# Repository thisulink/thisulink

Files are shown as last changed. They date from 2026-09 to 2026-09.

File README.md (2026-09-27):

# THISULINK™ — Enterprise Diabetic Complication Screening & Tele-Triage Platform

THISULINK™ is a closed-loop clinical network for diabetic complication
screening. It connects routine home monitoring, frontline point-of-care
diagnostics and specialist tele-consultation into one continuous pathway, with
an automated four-tier triage engine deciding where scarce clinical attention
goes.

The platform screens for the two complications that cause the most avoidable
harm and are the least visible on examination: **diabetic foot ulceration**,
detected through plantar shear-wave elastography and contralateral
thermography, and **diabetic retinopathy**, detected through non-mydriatic
fundus imaging with on-device AI grading.

**Status: deployed and operational**, with a hardened backend, verified
role-based access control and an end-to-end validated triage loop.

---

## 1. System architecture

```
 ┌──────────────────────────── TIER 1 · HOME ───────────────────────────────┐
 │  Patient Health Companion                                                │
 │  COTS BP cuff (0x1810) · glucometer (0x1808) · adherence · AI diet       │
 └────────────────────────────────┬─────────────────────────────────────────┘
                                  │ daily vitals
                                  ▼
 ┌──────────────────────── TIER 2 · POINT OF CARE ──────────────────────────┐
 │  Clinical Diagnostic Suite — community health worker                     │
 │                                                                          │
 │   Plantar probe (BLE 0xFFE0)        20D retinal adapter                  │
 │   • VCA 10–300 Hz sweep             • non-mydriatic, 60 s                │
 │   • dual ADXL355, Δx = 40 mm        • EfficientNet-B0 INT8 on-device     │
 │   • TAL221 interlock 1.40–1.60 N    • ICDR grade 0–4                     │
 │   • MLX90621 16×4 FIR, ΔT ≥ 2.2 °C                                       │
 │                                                                          │
 │   Offline-first · encrypted local store · queue and retry                │
 └────────────────────────────────┬─────────────────────────────────────────┘
                                  │ encounter upload
                                  ▼
 ┌──────────────────────── TIER 3 · CLOUD ENGINE ───────────────────────────┐
 │  PocketBase enterprise core — https://pb.thisulink.xyz                   │
 │                                                                          │
 │   Authentication & zero-trust RBAC   Automated triage engine             │
 │   Realtime event bus (SSE)           Immutable audit trail               │
 │   Clinical file storage              Escalation dispatch                 │
 └────────────────────────────────┬─────────────────────────────────────────┘
                                  │ realtime, risk-ranked
                                  ▼
 ┌──────────────────────── TIER 4 · SPECIALIST ─────────────────────────────┐
 │  Clinical Workstation — https://thisulink.xyz                            │
 │                                                                          │
 │   🔴 Critical → 🟠 Priority → 🟡 Moderate → 🟢 Stable                     │
 │   Waveform & FFT review · fundus grading & override                      │
 │   Signed prescriptions · diet approval · LiveKit consultation            │
 └──────────────────────────────────────────────────────────────────────────┘
```

The loop closes: every reading triggers a server-side triage recomputation,
which updates the patient's tier, writes an audit row, and — on escalation into
a priority tier — dispatches an alert back to the health worker in the field.

---

## 2. Production endpoints

| Endpoint | Serves | TLS | Status |
|---|---|---|---|
| **https://thisulink.xyz** | Specialist Clinical Workstation | Cloudflare edge | **200** |
| **https://doctor.thisulink.xyz** | Workstation, named ingress | Cloudflare edge | **200** |
| **https://pb.thisulink.xyz** | Backend REST + realtime gateway | Cloudflare edge | **200** |
| `https://pb.thisulink.xyz/_/` | Administration console | — | **404 — blocked at edge** |
| `http://<tailscale-ip>:8090/_/` | Administration console | Private mesh | Mesh only |

### Edge security rules

| Rule | Enforcement |
|---|---|
| `/_/*` returns 404 publicly | Reverse proxy at the origin |
| `/api/admins` returns 404 publicly | Reverse proxy at the origin |
| No inbound ports on the origin | Outbound-initiated Cloudflare tunnel |
| Default-deny firewall | Mesh interface and SSH only |
| Administration access | Private Tailscale mesh exclusively |

Full topology and operations: **[backend/INFRASTRUCTURE.md](backend/INFRASTRUCTURE.md)**

---

## 3. Access credentials

| Role | Endpoint | Email | Password |
|---|---|---|---|
| **Physician** | https://thisulink.xyz | `doctor@thisulink.xyz` | `Doctor@Thisu2026` |
| **Health worker** | Clinical Diagnostic Suite (Android) | `healthworker@thisulink.xyz` | `Worker@Thisu2026` |
| **Patient** | Health Companion *(roadmap)* | `patient@thisulink.xyz` | `Patient@Thisu2026` |
| **Administrator** | `http://<tailscale-ip>:8090/_/` | `admin@thisulink.xyz` | `AdminSecure#2026` |

**Patient ABHA:** `9145-2388-9100-21`

> The administration console is unreachable from the public internet by design.
> Rotate every credential above before any deployment carrying real patient
> data — they are published here for evaluation.

### Verified access isolation

| Account | patients | plantar | vitals | retinal |
|---|---|---|---|---|
| `doctor` | 4 | 24 | 24 | 4 |
| `health_worker` | 4 | 24 | 24 | 4 |
| **`patient`** | **0** | **0** | **0** | **0** |

---

## 4. Documentation index

| # | Document | Subsystem |
|---|---|---|
| 1 | **This file** | Master architecture & deployment directory |
| 2 | [hardware/README.md](hardware/README.md) | Foot platform — actuator, interlock, sensor geometry, thermal array |
| 3 | [hardware/BLE_SPECIFICATION.md](hardware/BLE_SPECIFICATION.md) | 73-byte telemetry contract, GATT profile, CRC |
| 4 | [vitals-monitor/README.md](vitals-monitor/README.md) | COTS BLE vitals — `0x1810` / `0x1808` |
| 5 | [retinal-screening/README.md](retinal-screening/README.md) | 20D adapter, quality gate, edge AI pipeline |
| 6 | [software/README.md](software/README.md) | Cross-platform client architecture |
| 7 | [software/daq-dashboard/README.md](software/daq-dashboard/README.md) | Frontline screening suite |
| 8 | [software/patient-app/README.md](software/patient-app/README.md) | Patient companion & daily compliance |
| 9 | [doctor-portal/README.md](doctor-portal/README.md) | Specialist workstation & triage workflows |
| 10 | [backend/README.md](backend/README.md) | Schema, RBAC, event engine |
| 11 | [backend/INFRASTRUCTURE.md](backend/INFRASTRUCTURE.md) | Tunnel, mesh, edge operations |
| 12 | [prototype-outputs/README.md](prototype-outputs/README.md) | Screen-by-screen prototype outputs & verification gallery |
| 13 | [firmware/README.md](firmware/README.md) | Embedded MCU firmware architecture (ESP32-S3 + DSP pipeline) |
| 14 | [platform matlab simulation and proofs/README.md](platform%20matlab%20simulation%20and%20proofs/README.md) | Plantar SWE simulation suite & mathematical proofs (12 experiments) |
| 15 | [Clinical_Datasets_and_Parameter_Conversion/README.md](Clinical_Datasets_and_Parameter_Conversion/README.md) | Clinical data sourcing, Kelvin-Voigt physics & parameter conversion |
| 16 | [hardware/cad/README.md](hardware/cad/README.md) | Prototype 3D CAD models, cross-sections & mechanical engineering specs |

### Specification ↔ source

The documentation tree is organised by **subsystem**; the source tree is
organised by **build artefact**. They map as follows:

| Specification | Implementation |
|---|---|
| `software/daq-dashboard/` | `thisulink_app` (Flutter, Android client) |
| `doctor-portal/` | `doctor_portal` (Flutter, Web workstation) |
| `backend/` | [`deploy/`](deploy/) — provisioning, schema, automation |
| `hardware/`, `vitals-monitor/`, `retinal-screening/` | Hardware & clinical telemetry contracts |

---

## 5. Resolved specification conflicts

Four conflicts across earlier drafts are closed. These resolutions are binding.

| # | Conflict | Resolution |
|---|---|---|
| 1 | **BLE frame header** | **`0x5448`** (ASCII `"TH"`). The draft value `0xDA 0x7A` is **permanently deprecated** and must not appear in firmware, clients, fixtures or documentation. |
| 2 | **Blood pressure sensing** | **COTS oscillometric devices** over Bluetooth SIG `0x1810`, ISO 81060-2 validated. The cuffless optical PPG model is **removed** — it has no accepted validation standard and fails by returning a plausible wrong number. |
| 3 | **Thermal sensing** | **Melexis MLX90621**, 16 × 4 = 64-pixel FIR array. Alert on contralateral asymmetry **ΔT ≥ 2.2 °C** (Lavery et al., 2007). |
| 4 | **Authorisation model** | **Explicit allowlist** on `@request.auth.role`. Negative exclusion rules are prohibited — see below. |

### Why the authorisation model is a resolution, not a preference

A negative exclusion (`role != "patient"`) evaluates **true** when `role` is
absent. During production verification this admitted every authenticated
account to every clinical collection, because a schema defect meant no account
had a role at all. A patient account could read all 24 plantar records, 24
vitals, 4 fundus evaluations and 8 triage results.

An allowlist denies the same account. The two forms behave **oppositely**
under exactly the condition nobody writes a test for. Full incident analysis:
[backend/README.md §4.1](backend/README.md).

---

## 6. Clinical triage specification

| Tier | Condition — first match wins | Action |
|---|---|---|
| 🔴 **RED** | Tissue class C, **or** P(referable) ≥ 0.50 with ICDR ≥ 3, **or** glucose > 400 mg/dL | Refer urgently |
| 🟠 **ORANGE** | Class B with ΔT ≥ 2.2 °C, **or** P(referable) ≥ 0.50, **or** glucose > 300 | Escalate to specialist |
| 🟡 **YELLOW** | Class B, **or** ΔT ≥ 2.2 °C, **or** ICDR ≥ 2, **or** glucose > 180 | Monitor, recheck next cycle |
| 🟢 **GREEN** | None of the above | No action |

### Clinical constants

| Constant | Value | Governs |
|---|---|---|
| Preload interlock | **1.40 – 1.60 N** | Scan validity |
| Thermal asymmetry alert | **ΔT ≥ 2.2 °C** | Ulcer-risk escalation |
| Referable DR threshold | **P ≥ 0.50** | Retinal escalation |
| Excitation sweep | **10 – 300 Hz** | Shear-wave acquisition |
| Pickup baseline | **Δx = 40 mm** (x₁ 105 mm, x₂ 145 mm) | Phase velocity |
| Screening cycle | **6 days** | Fundus on days 1 and 4 |
| Relay escalation | **4 hours** | Unacknowledged priority tier |

---

## 7. Verification status

### Verified against the live deployment

| Check | Result |
|---|---|
| Static analysis — both shipped clients | Clean |
| Automated tests — field client | **63 passing** |
| Schema provisioning | 8 collections, rules confirmed in database |
| **Role-based access isolation** | **Verified — patient sees zero clinical records** |
| **Triage engine, end to end** | **Correct tier for every patient** |
| **Escalation dispatch** | **Alert raised on tier entry with clinical reasoning** |
| Administration console exposure | 404 public, mesh-only |
| Public endpoints | 3 hostnames serving |

### Verified tier assignment

| Patient | Tissue | ΔT | Glucose | ICDR | Tier |
|---|---|---|---|---|---|
| Meena Devi | C | 2.7 °C | 262 | 4 | 🔴 RED |
| Saravanan S | B | 2.4 °C | 216 | 2 | 🟠 ORANGE |
| Ravi Kumar | B | 1.9 °C | 168 | 1 | 🟡 YELLOW |
| Arjun Prakash | A | 1.2 °C | 138 | 0 | 🟢 GREEN |

### Outstanding before clinical use

| Item | Status |
|---|---|
| **Probe firmware validation** | Decoder byte-exact and tested; never run against physical hardware |
| **Retinal model asset** | Inference pipeline implemented; trained INT8 model not bundled |
| **Retinal image quality gate** | Not implemented — required before grading is trusted |
| **Tele-consultation token service** | Not deployed; consultations cannot start |
| **Patient Health Companion** | Not implemented; backend role and record are live |
| **Database backups** | **Not configured** |
| **Redundancy** | **Single node** |

---

## 8. Quickstart

### Backend

```bash
curl -s https://pb.thisulink.xyz/api/health
sudo systemctl status thisulink-pocketbase
```

### Specialist Clinical Workstation

```bash
cd doctor_portal
flutter pub get && cp .env.example .env
flutter run -d chrome --web-port=8080
flutter build web --release
```

### Clinical Diagnostic Suite

```bash
cd thisulink_app
flutter pub get
dart run build_runner build
flutter run                           # live backend
flutter run --dart-define=DEMO=true   # seeded, no backend required
flutter test                          # 63 tests
```

### Provisioning a new node

```bash
sudo ./deploy/bootstrap.sh --purge-existing --apply-ingress
sudo ./deploy/finish.sh
sudo ./deploy/seed.sh
./deploy/verify.sh
```

---

## 9. Regulatory positioning

THISULINK™ is **clinical decision support**. It stratifies risk and presents
evidence; a licensed clinician makes every clinical decision. That boundary is
enforced in the product — the intended-use notice is present on every page of
the workstation, physician override supersedes every AI output, and no tier is
communicated to a patient without a clinician.

Documentation is structured for **IEC 62304** alignment: each subsystem carries
a controlled specification, interfaces are contract-specified before
implementation, and verification status is stated per component rather than in
aggregate.

---

<div align="center">

**THISULINK™** · Clinical decision support for diabetic complication screening
Screening outputs are authorised by a licensed clinician.

</div>

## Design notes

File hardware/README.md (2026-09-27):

# THISULINK™ Plantar Diagnostic Platform — Hardware Specification

| | |
|---|---|
| **Document** | HW-SPEC-001 |
| **Subsystem** | Plantar Shear-Wave Elastography & Thermography Platform |
| **Wire contract** | [BLE_SPECIFICATION.md](BLE_SPECIFICATION.md) |
| **Status** | Design specification — see §9 for build status |

---

## 1. Clinical purpose

Diabetic foot ulceration is preceded by changes that are invisible on
inspection: the plantar soft tissue stiffens as collagen glycates, and a
developing inflammatory focus raises local temperature before any break in the
skin. Both are measurable non-invasively, and both are missed by a visual
screening exam.

The platform measures two independent physical signals at the same site in the
same sitting:

| Signal | Physical basis | Clinical meaning |
|---|---|---|
| **Shear-wave speed / Young's modulus** | Surface wave propagation through plantar soft tissue | Tissue stiffening from advanced glycation end-product accumulation |
| **Contralateral thermal asymmetry ΔT** | Non-contact far-infrared emission | Localised inflammation preceding ulceration |

Neither measurement diagnoses. Together they stratify risk, and the platform's
job is to make that stratification reproducible enough that a health worker
with a week of training produces the same numbers as a clinician.

---

## 2. Architecture

```
                 THISULINK PLANTAR PLATFORM
    ┌──────────────────────────────────────────────────────┐
    │                                                      │
    │   ┌────────────┐         PLANTAR SURFACE             │
    │   │  MLX90621  │  ◄── non-contact FIR, 16×4          │
    │   │  16×4 FIR  │      64 pixels, contralateral ΔT    │
    │   └────────────┘                                     │
    │                                                      │
    │   ═══════════════════════════════════════════        │
    │        ▲             ▲                ▲              │
    │        │             │                │              │
    │   ┌────┴────┐   ┌────┴────┐     ┌─────┴─────┐        │
    │   │   VCA   │   │ ADXL355 │     │  ADXL355  │        │
    │   │ 10–300Hz│   │ pickup 1│     │  pickup 2 │        │
    │   │ 0.100 N │   │ x₁=105mm│     │  x₂=145mm │        │
    │   └─────────┘   └─────────┘     └───────────┘        │
    │                 └──── Δx = 40 mm baseline ────┘      │
    │                                                      │
    │   ┌──────────────────────────────────────┐           │
    │   │  TAL221 load cell  →  HX711 24-bit   │           │
    │   │  preload interlock 1.40 – 1.60 N     │           │
    │   └──────────────────────────────────────┘           │
    │                                                      │
    │   ┌──────────────────────────────────────┐           │
    │   │  MCU · BLE 5.0 · GATT 0xFFE0         │           │
    │   │  73-byte frame @ 0xFFE1 (notify)     │           │
    │   └──────────────────────────────────────┘           │
    └──────────────────────────────────────────────────────┘
                              │
                              ▼  BLE 5.0
                   Clinical Diagnostic Suite (tablet)
```

---

## 3. Excitation — voice coil actuator

| Parameter | Value |
|---|---|
| Actuator type | Voice coil (VCA), direct-drive |
| Sweep range | **10 – 300 Hz** |
| Dynamic force | **0.100 N** |
| Sweep duration | 200 ms per acquisition |
| Coupling | Medical-grade silicone pad |

The band is chosen for tissue, not convenience. Below ~10 Hz the response is
dominated by bulk limb motion; above ~300 Hz attenuation in soft tissue makes
the second pickup's signal-to-noise unusable across a 40 mm baseline.

Dynamic force is held at 0.100 N — two orders below the static preload — so the
excitation perturbs the tissue without changing the loading state being
measured.

---

## 4. Preload interlock

| Component | Specification |
|---|---|
| Load cell | TAL221 cantilever, 5 kg (≈50 N) capacity |
| ADC | HX711, 24-bit, integrated gain |
| Sample rate | 80 SPS |
| **Valid window** | **1.40 N – 1.60 N** |
| Out-of-window behaviour | Sample flagged, excluded from averaging |
| Wander behaviour | Auto-abort if preload leaves the window mid-sweep |

### Why an interlock rather than a correction

Soft tissue is non-linear and load-dependent: its apparent stiffness rises with
applied force. A shear-wave measurement taken at 2.5 N and one at 1.5 N are not
the same measurement with different noise — they are measurements of different
mechanical states.

Two options exist: measure the force and correct for it, or constrain the force
and refuse to measure outside the constraint. The platform constrains, because
correction requires a per-patient tissue model the device does not have. A
rejected scan costs thirty seconds. A silently load-biased scan enters the
clinical record and is indistinguishable from a real finding.

### Tare procedure

The load cell is zeroed via the `TARE` command (§3.2 of the BLE specification)
at rest before each encounter, compensating for platform orientation and
accumulated mechanical drift.

---

## 5. Surface wave sensing

| Parameter | Value |
|---|---|
| Sensors | 2 × Analog Devices ADXL355, low-noise triaxial MEMS |
| Pickup 1 position | x₁ = **105 mm** from actuator axis |
| Pickup 2 position | x₂ = **145 mm** from actuator axis |
| Baseline | **Δx = 40 mm** |
| Sampling | Synchronous, shared clock |

### Phase velocity derivation

Shear-wave speed is computed from the phase difference between the two pickups
at each sweep frequency:

> **cₛ = ω · Δx / Δφ**

where ω is angular excitation frequency, Δx the 40 mm baseline, and Δφ the
measured phase delay.

Young's modulus follows from the shear-wave speed under a near-incompressible
soft-tissue assumption:

> **E ≈ 3ρcₛ²**

with ρ taken as soft-tissue density.

### Why two sensors rather than time-of-flight

A phase-difference measurement across a **fixed, known** baseline is
insensitive to the absolute trigger instant and to actuator latency, both of
which drift with temperature and mechanical wear. A single-sensor
time-of-flight approach inherits every one of those errors directly into the
reported speed.

The baseline is the one dimension that must not move: Δx appears linearly in
cₛ, so a 1 mm mounting error is a 2.5% systematic error in every reading the
device ever produces. Pickup spacing is therefore fixed in the moulded
housing, not adjustable.

---

## 6. Thermal mapping

| Parameter | Value |
|---|---|
| Sensor | **Melexis MLX90621**, far-infrared thermopile array |
| Resolution | **16 × 4 = 64 pixels** |
| Measurement | Non-contact, no thermal loading of the site |
| Field of view | Matched to plantar region of interest |
| **Alert threshold** | **ΔT ≥ 2.2 °C** contralateral asymmetry |

### Contralateral comparison

Absolute plantar temperature varies with ambient conditions, recent activity,
footwear and perfusion — none of which indicate pathology. The clinically
meaningful quantity is the **difference between corresponding sites on the two
feet**, measured in the same session under the same conditions.

The 2.2 °C threshold follows Lavery et al. (2007), which established
contralateral asymmetry at this magnitude as predictive of impending
ulceration. Both feet are imaged in the same encounter; a single-foot capture
cannot produce a valid ΔT and is rejected at the application layer.

### Why a 64-pixel array

A single-point IR thermometer measures wherever it is aimed. An inflammatory
focus is localised, so a point measurement a centimetre away from it reads
normal. The 16×4 array covers the region of interest in one capture, removing
operator aim from the measurement.

---

## 7. Mechanical housing

| Element | Specification |
|---|---|
| Enclosure | 3D-printed PETG |
| Acoustic coupling | Medical-grade silicone interface pad |
| Vibration isolation | Rubberised damping feet |
| Sensor mounting | Rigid, fixed 40 mm pickup baseline |

PETG is specified over PLA for dimensional stability at clinic temperatures and
for its tolerance of repeated surface disinfection.

The damping feet serve the measurement, not comfort: without isolation, the
VCA excitation couples into the examination surface and returns to the pickups
as a structural path parallel to the tissue path, corrupting the phase
difference the entire instrument depends on.

> Complete mechanical engineering CAD models, cross-sectional schematics, and OpenSCAD parametric files: **[cad/README.md](cad/README.md)**.

---

## 8. Interface summary

| Interface | Specification |
|---|---|
| Wireless | Bluetooth Low Energy 5.0 |
| Service | `0xFFE0` |
| Telemetry | `0xFFE1`, notify, 73 bytes |
| Control | `0xFFE2`, write, 4 bytes |
| Frame header | `0x5448` (`"TH"`) |
| Integrity | CRC-8/MAXIM over bytes 0–71 |

Full byte-level contract: **[BLE_SPECIFICATION.md](BLE_SPECIFICATION.md)**.

---

## 9. Implementation status

| Item | Status |
|---|---|
| Mechanical and sensing design | Specified |
| BLE wire contract | Specified, frozen at v1.0 |
| Client-side decoder | Implemented, 18 conformance tests passing |
| Client-side interlock enforcement | Implemented |
| Tissue classification bands | Implemented, unit-tested |
| **Probe firmware** | **Not validated against this document** |
| **End-to-end acquisition on hardware** | **Not yet performed** |

The software half of this interface is complete and tested against the
specification. The specification has not been confirmed against a physical
probe. Section 8 of the BLE specification is the checklist that closes that
gap, and it must be executed on-target before any clinical use.

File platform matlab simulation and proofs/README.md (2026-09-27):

# THISULINK: Plantar Biomechanical SWE Platform — MATLAB Simulation Suite & Engineering Proofs






---

## 1. Executive Summary & Problem Context

**THISULINK** is an integrated dual-modality frontline triage device engineered for **Frontline Health Workers (VHN / ANM / CHO)** to prevent diabetic lower-limb amputations and diabetic retinopathy in under-resourced communities.

This folder contains the **mechanical, biomechanical, electromechanical, and sensor-level simulation suite** (MATLAB / GNU Octave) used to size and sanity-check the **THISULINK Plantar Shear Wave Elastography (SWE) Platform**.

> **Scope:** every result in this folder is a *simulation* with assumed parameters and synthetic data. Nothing here is a bench measurement or clinical evidence. See [Section 8 - Limitations](#8-limitations).

### Why Biomechanical SWE on the Plantar Foot?
Standard clinical triage uses 10-gram monofilaments or tuning forks, which only identify nerve loss after irreversible neuro-ischaemic destruction has occurred. Long before sensory loss, **non-enzymatic glycation** of collagen fibers in the plantar fat pad and fascia causes severe tissue stiffening, loss of energy damping, and elevated shear stresses that cause plantar ulceration.

THISULINK launches non-invasive, low-frequency shear waves ($10 - 300\text{ Hz}$) into the plantar tissue using a precision Voice Coil Actuator (VCA), and tracks wave propagation using dual low-noise digital accelerometers (Analog Devices ADXL355). This allows quantitative extraction of shear wave velocity ($c_s$) and Young's modulus ($E = 3\rho c_s^2$) months before visible lesions or ulceration appear.

```
+---------------------------------------------------------------------------------------+
|                                THISULINK HARDWARE ARCHITECTURE                        |
+---------------------------------------------------------------------------------------+
|                                                                                       |
|   +-------------------+        +--------------------+        +--------------------+   |
|   | Voice Coil (VCA)  |        | Proximal Pickup    |        | Distal Pickup      |   |
|   | 10 - 300 Hz Chirp |=======>| ADXL355 Sensor 1   |=======>| ADXL355 Sensor 2   |   |
|   | F0 = 100 mN       |        | x1 = 105 mm        |        | x2 = 145 mm        |   |
|   +-------------------+        +--------------------+        +--------------------+   |
|            ^                              |                             |             |
|            |                              +--------------+--------------+             |
|            |                                             |                            |
|     +-------------+                        [Phase Difference Delta phi]               |
|     | Load Cell   |                                      |                            |
|     | 1.50 N Gate |                        c_s = (omega * Delta x) / Delta phi        |
|     +-------------+                        E = 3 * rho * c_s^2                        |
|            |                                             |                            |
|    [Preload Interlock]                                   v                            |
|    (1.40 N - 1.60 N)                       +----------------------------+             |
|                                            | THISULINK TRIAGE ENGINE    |             |
|                                            | SWE Modulus + FIR Thermal  |             |
|                                            +----------------------------+             |
+---------------------------------------------------------------------------------------+
```

---

## 2. Platform Mechanical & Hardware Architecture

| Subsystem | Component | Specifications | Clinical / Physical Justification |
|---|---|---|---|
| **Dynamic Actuator** | Linear Voice Coil Actuator (VCA) | $m = 0.045\text{ kg}$, $R = 8.2\ \Omega$, $L = 1.2\text{ mH}$, $K_f = 2.4\text{ N/A}$ | Provides pure decoupled sinusoidal chirp ($10 - 300\text{ Hz}$), eliminating motor harmonic distortion. |
| **Contact Interlock** | Cantilever Micro Load Cell + HX711 | $1.50\text{ N} \pm 0.10\text{ N}$ ($1.40 - 1.60\text{ N}$ allowable gate) | Prevents operator variability and eliminates non-linear hyperelastic tissue pre-compression artifacts. |
| **Pickup Transducers** | Dual ADXL355 Accelerometers | 20-bit ADC, $25\ \mu\text{g}/\sqrt{\text{Hz}}$, $\pm 2.048\text{ g}$, simulated at ODR $4\text{ kHz}$ (LPF $\approx 1\text{ kHz}$) | Simulated 50 Hz phase error $\approx 0.1^\circ$ at the distal pickup (Exp. 06). The current POC firmware uses an ADXL345 at 200 Hz ODR (Nyquist 100 Hz) and cannot cover the full sweep. |
| **Gauge Separation** | Rigid CNC Base Frame | $x_1 = 105\text{ mm}$, $x_2 = 145\text{ mm}$, $\Delta x = 40.0\text{ mm}$ | Inter-sensor phase exceeds $\pi$ above $\approx 46-110\text{ Hz}$ (class dependent), so the sweep must be phase-unwrapped across frequency (Exp. 10). |
| **Tremor Restraint** | Medical Velcro Stabilization Straps | Dual instep & heel belts ($k_{\text{strap}} = 12,000\text{ N/m}$, assumed) | Simulated: an assumed $1.5\text{ mm}$ free-foot tremor ($2 - 5\text{ Hz}$) is reduced to $0.02\text{ mm}$ ($98.7\%$, Exp. 11). |
| **Guide Flexures** | Beryllium Copper Planar Springs | Lateral stiffness $k_{\text{lat}} = 7,500\text{ N/m}$ | Guides normal excitation ($Z$-axis) while clamping rocking and transverse shear motion. |
| **Thermal Sensing** | MLX90621 $16 \times 4$ FIR Array | Differential bilateral sensing, NETD $0.1^\circ\text{C}$ | Detects acute neuropathic inflammation / Charcot warning ($\Delta T_{\text{contra}} \ge 2.2^\circ\text{C}$). |

---

## 3. Plantar Soft-Tissue Biomechanical Classes

The simulation models **three preliminary research mechanical-response bands** of diabetic plantar tissue remodeling ($\rho = 1050\text{ kg/m}^3$). These bands are derived from the Kelvin-Voigt viscoelastic model and literature-sourced tissue parameters — they are not clinically validated stages. Human-subject confirmation against biopsy or established clinical markers has not been performed.

```
+---------------------------------------------------------------------------------------------------------+
|                                    DIAGNOSTIC BIOMECHANICAL CLASSES                                     |
+-------------------+-----------------+-----------------+--------------------+------------------+---------+
| Diagnostic Class  | Contact k (N/m) | Shear Mod. (Pa) | Shear Speed (m/s)  | Young's Modulus  | Damping |
+-------------------+-----------------+-----------------+--------------------+------------------+---------+
| Class 1: Healthy  | 800 N/m         | 14.5 kPa        | 3.72 m/s           | 43.5 kPa         | 2.5 Ns/m|
| Class 2: Early    | 1500 N/m        | 32.0 kPa        | 5.52 m/s           | 96.0 kPa         | 3.2 Ns/m|
| Class 3: Severe   | 2600 N/m        | 68.0 kPa        | 8.05 m/s           | 204.0 kPa        | 4.5 Ns/m|
+-------------------+-----------------+-----------------+--------------------+------------------+---------+
```

---

## 4. Directory Structure & Simulation Modules

```
platform matlab simulation and proofs/
├── master_run_all.m                                  # Runs all 12 experiments, isolated; PASS/FAIL table
├── README.md                                         # This file
├── .gitignore                                        # ignores legacy */results/ folders
├── common/
│   ├── simulation_parameters.m                       # Shared parameters (script; does not clear anything)
│   ├── tissue_model.m                                # 1-DOF Kelvin-Voigt contact ODE
│   ├── shear_wave_propagation_model.m                # 1-D viscoelastic propagation to a pickup (fractional delay)
│   ├── run_experiment_isolated.m                     # Runs one script in its own workspace, restores path/folder
│   ├── det_randn.m                                   # Deterministic normal RNG (same numbers in MATLAB and Octave)
│   ├── fourier_pair.m                                # Coherent single-tone amplitude/phase of two signals
│   ├── results_folder.m                              # outputs/<experiment>/ helper
│   └── bar_colored.m                                 # Per-bar coloured bar chart (MATLAB + Octave)
├── 01_Baseline_Mechanical_Response/                  # 1.5 N preload + 100 mN, 50 Hz response
├── 02_Stiffness_Comparison/                          # Healthy vs early glycation vs neuropathy
├── 03_Frequency_Sweep/                               # 10-300 Hz FRF & resonance shift
├── 04_FFT_Analysis/                                  # Hann-windowed FFT & THD pipeline
├── 05_Sensor_Simulation/                             # Dual ADXL355 digitisation, broadband vs narrow-band SNR
├── 06_Noise_SNR_Analysis/                            # Noise-density sweep, 50 Hz phase error
├── 07_Contact_Force_Sensitivity/                     # Preload stiffening & 1.50 N interlock window
├── 08_Load_Cell_Validation/                          # Load-cell interlock decision logic
├── 09_VCA_Electrical_Test/                           # VCA impedance, current, force, power
├── 10_Shear_Wave_Dispersion_and_Modulus/             # Phase velocity, unwrapping, Kelvin-Voigt modulus fit
├── 11_Velcro_and_Flexure_Tremor_Suppression/         # Tremor suppression by straps + flexures
├── 12_Comprehensive_Triage_Scoring/                  # SWE + thermal triage on a synthetic cohort
└── outputs/                                          # Generated figures + run log - see outputs/README.md
```

---

## 5. Mathematical Formulations & Derivations

### 5.1 Kelvin-Voigt Viscoelastic Wave Propagation
Plantar tissue dynamics under harmonic voice coil excitation:
$$m \ddot{x}(t) + c \dot{x}(t) + k x(t) = F_0 \sin(\omega t)$$

Complex shear modulus:
$$G^*(\omega) = \mu + j \omega \eta$$

Viscoelastic phase velocity $c_s(\omega)$ and spatial attenuation $\alpha(\omega)$:
$$c_s(\omega) = \sqrt{\frac{2(\mu^2 + \omega^2 \eta^2)}{\rho\left(\mu + \sqrt{\mu^2 + \omega^2 \eta^2}\right)}}$$
$$\alpha(\omega) = \sqrt{\frac{\rho \omega^2\left(\sqrt{\mu^2 + \omega^2 \eta^2} - \mu\right)}{2(\mu^2 + \omega^2 \eta^2)}}$$

### 5.2 Dual Pickup Phase Difference Method
Given two ADXL355 pickups at $x_1 = 105\text{ mm}$ and $x_2 = 145\text{ mm}$ ($\Delta x = 40.0\text{ mm}$):
$$\Delta \phi(\omega) = \angle X_1(\omega) - \angle X_2(\omega) \quad (\text{distal lags proximal})$$
$$c_s(\omega) = \frac{\omega \cdot \Delta x}{\Delta \phi(\omega)}$$

**Phase wrapping:** $\Delta\phi$ exceeds $\pi$ above $f = c_s/2\Delta x$ (about 46-110 Hz for $c_s$ = 3.7-8 m/s) and $2\pi$ above $f = c_s/\Delta x$. Experiment 10 measures a stepped sine from 20 Hz and unwraps along frequency; a single-frequency estimate is only safe at low frequency (50 Hz is used for the nominal measurement).

Plantar tissue Young's Modulus $E$ (for nearly incompressible tissue $\nu \approx 0.499$):
$$E \approx 3\mu = 3\rho \cdot c_s^2$$

### 5.3 Tremor Suppression Model (Velcro Straps + Flexures)
$$\left(m_{\text{foot}}\right) \ddot{x} + \left(c_{\text{free}} + c_{\text{strap}}\right) \dot{x} + \left(k_{\text{free}} + k_{\text{strap}} + k_{\text{flex}}\right) x = F_{\text{tremor}}(t)$$

With THISULINK restraints:
$$k_{\text{eff}} = 500 + 12000 + 7500 = \mathbf{20,000\text{ N/m}} \quad (\text{40-fold rigidity increase})$$
With an assumed $1.50\text{ mm}$ free-foot tremor, the simulated clamped amplitude is $0.0195\text{ mm}$ ($98.7\%$ attenuation, Experiment 11).

---

## 6. How to Run the Simulations

### Prerequisites
- MATLAB R2018b or newer (uses `xline`/`yline`), **no toolboxes required**, or
- GNU Octave (tested with **11.3**, no packages required).

### Whole suite
```matlab
% from the folder "platform matlab simulation and proofs"
master_run_all
```
```bash
matlab -batch "master_run_all"
octave --no-gui --eval "master_run_all"   # Windows: use octave-gui.exe --no-gui (qt) so PNG export works
```
- Each experiment runs in its own workspace (`common/run_experiment_isolated.m`); the path and current folder are restored afterwards, a failing experiment is reported and the suite continues.
- Figures go to `outputs/<experiment>/`, the console log to `outputs/master_run_log.txt`. The committed copies
  are indexed with captions in **[outputs/README.md](outputs/README.md)**; re-running the suite overwrites them.
- Runtime ~30 s. On Windows keep the clone path short: Octave cannot write files whose full path exceeds 260 characters.

### Expected output (GNU Octave 11.3, Windows)
```
Exp  Module                                       Result  Time (s)
01   01_Baseline_Mechanical_Response              PASS        2.24
02   02_Stiffness_Comparison                      PASS        3.01
03   03_Frequency_Sweep                           PASS        1.79
04   04_FFT_Analysis                              PASS        1.01
05   05_Sensor_Simulation                         PASS        1.79
06   06_Noise_SNR_Analysis                        PASS        1.68
07   07_Contact_Force_Sensitivity                 PASS        1.99
08   08_Load_Cell_Validation                      PASS        1.53
09   09_VCA_Electrical_Test                       PASS        1.82
10   10_Shear_Wave_Dispersion_and_Modulus         PASS        4.55
11   11_Velcro_and_Flexure_Tremor_Suppression     PASS        2.21
12   12_Comprehensive_Triage_Scoring              PASS        2.31
Passed: 12 / 12
```
"PASS" means the script ran to completion without error; the engineering checks each experiment prints are listed in its README.

### Running individual experiments
```matlab
cd('10_Shear_Wave_Dispersion_and_Modulus')
experiment_shear_wave
```

---

## 7. Simulation Evidence Index

All figures below are outputs of the scripts with the parameters in `common/simulation_parameters.m`.

| Topic | Simulated result | Experiment |
|---|---|---|
| Motion amplitude | 50 Hz steady-state displacement 0.027 mm (healthy) to 0.043 mm (neuropathy) at $F_0$ = 100 mN | 01, 02 |
| Resonance shift | $f_n$ 21.2 → 29.1 → 38.3 Hz; acceleration FRF peaks at 22 / 30 / 40 Hz | 02, 03 |
| Sensor noise | 50 Hz phase error ≈ 0.1° at 25 µg/√Hz; narrow-band SNR ≈ 55 dB at the distal pickup (broadband 18 dB) | 05, 06 |
| Preload control | 0.8-3.0 N gives -15.8 % to +33.8 % stiffness error; inside 1.40-1.60 N ≤ 2.25 % (assumed linear stiffening) | 07, 08 |
| Actuator power | 87.6 mW coil dissipation at 1.20 V; only 0.34 V needed for 100 mN (static-coil model) | 09 |
| Modulus reconstruction | 50 Hz apparent $E$ biased +1 to +5 % by viscosity; Kelvin-Voigt fit over the unwrapped usable band recovers $E$ within 1 % (same model used to generate the data) | 10 |
| Usable band | attenuation limits distal SNR ≥ 20 dB to 20-100 / 140 / 200 Hz (healthy / early / neuropathy) | 10 |
| Tremor suppression | assumed 1.5 mm free tremor → 0.0195 mm clamped (98.7 %, 39 dB in 2-5 Hz) | 11 |
| Triage rules | **SIMULATION on synthetic data:** 99.17 % 4-class agreement (119/120), Charcot flag 100 % sens./spec. on a synthetic N = 120 cohort. Not clinical accuracy. | 12 |

The previously quoted "94.2 % diagnostic accuracy, 100 % sensitivity" is withdrawn: it came from an older script version, was not reproducible, and in any case described synthetic data only.

---

## 8. Limitations
- **Parameters are assumptions.** Tissue classes ($k$, $c$, $\mu$, $\eta$), strap/flexure stiffness, preload stiffening coefficient and cohort distributions are literature-inspired placeholders, not measurements.
- **Simplified physics.** 1-DOF contact model; 1-D narrow-band Kelvin-Voigt propagation with geometric spreading; no tissue layering, boundaries, finite contact size, skin coupling or sensor mounting dynamics.
- **Inverse crime.** Experiments 10 and 12 reconstruct data with the same model that generated it, so their accuracy figures are upper bounds.
- **Hardware.** The simulated sensor is the production dual-ADXL355 probe (ODR 4 kHz). The only existing firmware (ESP32-S3 + ADXL345, 200 Hz ODR, Nyquist 100 Hz) cannot sample the 10-300 Hz sweep. Actuator back-EMF and electronics power are not modelled.
- **No clinical claims.** Triage metrics describe separation of synthetic groups; clinical sensitivity/specificity require a prospective study.

---

## 9. Authors & License
**Project THISULINK**
Integrated Dual-Modality Frontline Diabetic Triage
Smart India Hackathon (SIH) 2026 Grand Finale
Repository: [https://github.com/thisulink/thisulink](https://github.com/thisulink/thisulink)
Licensed under the MIT License.

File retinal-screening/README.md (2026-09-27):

# THISULINK™ Retinal Screening — 20D Optical Adapter & Edge AI

| | |
|---|---|
| **Document** | RET-SPEC-001 |
| **Subsystem** | Non-mydriatic fundus capture and diabetic retinopathy grading |
| **Grading scale** | ICDR, grades 0–4 |
| **Status** | Pipeline implemented, model asset outstanding — see §8 |

---

## 1. Clinical purpose

Diabetic retinopathy is asymptomatic until it threatens sight, and it is
treatable when found early. Screening is therefore near-universally
recommended and near-universally under-delivered in rural settings: it requires
an ophthalmologist, a fundus camera, and usually pharmacological dilation.

This subsystem removes all three constraints from the *screening* step. It does
not replace an ophthalmologist — it decides, at the point of care, who needs
one.

---

## 2. Optical interface

| Parameter | Specification |
|---|---|
| Condensing lens | **+20 D** Volk indirect ophthalmoscopy lens |
| Mounting | Spring-clip smartphone adapter, camera-axis aligned |
| Static field of view | **46°** |
| Internal baffling | **60° knife-edge anti-glare baffles** |
| Illumination | Smartphone LED, diffused, continuous |
| Working distance | Fixed by adapter geometry |

### Optical principle

The +20 D lens forms a real, inverted aerial image of the retina between lens
and camera. The phone focuses on that aerial image rather than on the eye
itself — indirect ophthalmoscopy, mechanised so that the geometry is set by the
adapter instead of by the examiner's hand.

### Why the baffles matter

The dominant failure of naive phone-plus-lens fundus photography is the corneal
specular reflection: the illumination LED returns off the tear film directly
into the sensor, and the resulting flare sits over the posterior pole — exactly
the region being screened.

The 60° knife-edge baffles separate the illumination and imaging paths inside
the adapter so that the specular return falls outside the collection aperture.
This is what makes the capture reproducible by a health worker rather than a
skill acquired over months.

> Complete mechanical cross-sectional CAD schematic and specifications: **[hardware/cad/README.md](../hardware/cad/README.md#2-smartphone-20d-retinal-imaging-adapter-isometric-3d-cross-section)**.

---

## 3. Operational protocol

| Property | Value |
|---|---|
| Dilation | **None** — no pharmacological mydriasis |
| Duration | Approximately **60 seconds** per patient |
| Discomfort | None; no contact with the eye |
| Operator skill | Health worker, trained in-session |
| Eyes captured | Both, recorded separately |

### Non-mydriatic rationale

Dilating drops require a prescriber, impose 20–30 minutes of waiting, blur the
patient's vision for hours, and carry a small angle-closure risk. In a village
screening camp that combination reduces to: most patients are not screened.

Non-mydriatic capture accepts a smaller field of view in exchange for a screen
that can actually be delivered. The trade is deliberate: the posterior pole
visible without dilation contains the lesions that determine referability.

### Capture sequence

```
   1. Patient seated, ambient light reduced
   2. Adapter clipped to device, lens aligned to camera axis
   3. Operator positions to working distance — on-screen guide
   4. Right eye  → quality gate → capture → on-device grading
   5. Left eye   → quality gate → capture → on-device grading
   6. Both records written locally, queued for sync
```

---

## 4. Image quality gate

Grading is attempted **only** on images that pass an automated gate. This runs
before inference, on-device, while the patient is still in the chair.

| Check | Rejects | Operator prompt |
|---|---|---|
| **Blur** | Motion or defocus below sharpness floor | "Hold steady and retake" |
| **Illumination** | Under- or over-exposed; specular flare over the pole | "Reduce room light and retake" |
| **Disc centring** | Optic disc absent or outside the expected region | "Re-centre and retake" |

### Why the gate precedes the model

A classifier given an unreadable image does not abstain — it returns a
confident grade derived from noise. In a screening context that is worse than
no result, because a false "grade 0" removes the patient from follow-up
entirely.

The gate converts an ungradable image into a **retake while the patient is
present**, which costs fifteen seconds, rather than a false reassurance that
costs a referral.

---

## 5. Edge inference pipeline

| Parameter | Specification |
|---|---|
| Architecture | **EfficientNet-B0** |
| Quantisation | **INT8** |
| Runtime | ONNX Runtime / TensorFlow Lite, on-device |
| Input | 224 × 224 × 3 |
| Output | 5-class ICDR grade + referability probability |

### Preprocessing

```
   captured frame
        │
        ▼
   retina circle detection  ──► crop to the illuminated disc,
        │                       discarding black surround
        ▼
   square pad              ──► preserve aspect ratio; no anisotropic
        │                       stretch of lesion morphology
        ▼
   resize 224×224 (cubic)
        │
        ▼
   ImageNet mean/std normalisation
        │
        ▼
   INT8 inference
```

Aspect ratio is preserved by padding rather than stretching. Microaneurysms and
haemorrhages are graded partly on size and shape; anisotropic scaling distorts
exactly the features the model was trained on.

### Output contract

| Output | Type | Meaning |
|---|---|---|
| `predicted_dr_grade` | 0–4 | ICDR severity |
| `referable_dr_prob` | 0.0–1.0 | P(referable disease) |
| `referable_dr_flag` | boolean | **Grade ≥ 2** |

| ICDR grade | Description |
|---|---|
| 0 | No apparent retinopathy |
| 1 | Mild non-proliferative |
| 2 | Moderate non-proliferative |
| 3 | Severe non-proliferative |
| 4 | Proliferative |

### Why on-device

| Constraint | Consequence |
|---|---|
| Rural connectivity | Screening must complete with no uplink |
| Result timing | Patient is told the outcome before leaving |
| Data minimisation | Fundus images need not transit a network to be graded |
| Cost | No per-inference cloud charge per patient screened |

A cloud fallback endpoint exists for devices where on-device inference is
unavailable; it is the exception path, not the design.

---

## 6. Clinical integration

Results are written to `retinal_records` and participate in triage:

| Triage contribution | Threshold |
|---|---|
| RED | P(referable) ≥ 0.50 **and** grade ≥ 3 |
| ORANGE | P(referable) ≥ 0.50 |
| YELLOW | grade ≥ 2 |

### Physician override

The Specialist Clinical Workstation presents the fundus image with the model's
grade and probability, and the reviewing physician may record
`doctor_confirmed_grade`.

**The confirmed grade always supersedes the prediction — including when it is
0.** A physician recording "no retinopathy" over a model's grade 3 must not
have that decision silently reverted by a null-coalescing bug that treats 0 as
absent. This behaviour is explicitly covered by the triage engine's test suite.

---

## 7. Data handling

| Aspect | Handling |
|---|---|
| Storage | `retinal_records.image_file`, server-side file storage |
| Formats | JPEG, PNG |
| Maximum size | 10 MB per image |
| Laterality | `eye_side`: `left` \| `right`, recorded per image |
| Access | Staff roles only; patients have no access to the collection |
| Retention | Longitudinal — prior fundus images inform progression |

Each eye is a separate record. Retinopathy is frequently asymmetric, and a
merged bilateral record cannot represent a grade 3 right eye alongside a grade
0 left.

---

## 8. Implementation status

| Component | Status |
|---|---|
| `retinal_records` collection, relations, access rules | **Live in production** |
| Triage integration — grade and referability thresholds | **Live and verified** |
| Physician review, zoom/pan, override and sign-off UI | Implemented |
| Doctor-grade-supersedes-prediction logic | Implemented, unit-tested |
| Preprocessing chain and inference wiring | Implemented |
| **Trained INT8 model asset** | **Not bundled** |
| **Image quality gate** | **Not implemented** |
| **Optical adapter hardware** | **Not validated** |

Every surrounding path — capture, storage, review, override, triage — is live
and exercised with seeded grades. The model file
`thisulink_retinal_efficientnet_b0_int8.onnx` is not present in the bundle, so
on-device grading falls back to the configured server endpoint until it is
supplied.

**The quality gate is the gap that matters most.** Without it, the first
ungradable image produces a confident false grade, and §4 explains why that is
the one failure this subsystem must not have. It should be delivered with the
model asset, not after it.

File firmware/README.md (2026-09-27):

# THISULINK™ — Embedded Firmware Architecture

This directory houses the embedded firmware implementations powering the THISULINK point-of-care biomechanical diagnostic hardware.

---

## 1. Directory Structure

```
firmware/
└── thisulink-esp32s3-adxl345/
    └── arduino/
        └── thisulink_firmware/
            ├── thisulink_firmware.ino       # Main application loop & command router
            ├── ADXL345_Driver.h/.cpp        # SPI/I²C low-noise hardware driver
            ├── AcquisitionEngine.h/.cpp     # High-speed ring buffer & interrupt sampling
            ├── DSPFilters.h/.cpp            # Real-time biquad IIR filters & detrending
            ├── FFTEngine.h/.cpp             # 2048-pt Radix-2 Cooley-Tukey FFT & peak picker
            ├── FeatureExtractor.h/.cpp      # Time/frequency mechanical feature vector
            ├── SensorCalibration.h/.cpp     # Static gravity bias calibration
            ├── PositionManager.h/.cpp       # Multi-site anatomical scan manager
            ├── DataLogger.h/.cpp            # High-throughput serial/BLE telemetry logger
            ├── SerialConsole.h/.cpp         # Interactive ASCII diagnostics shell
            └── README.md                    # Detailed firmware DSP & architecture manual
```

---

## 2. Firmware Roles & Evolution

| Firmware Package | Platform / Target | Accelerometer | Status | Purpose |
|---|---|---|---|---|
| **`thisulink_firmware`** | ESP32-S3 DevKitC-1 | ADXL345 (13-bit) | Validated POC | Validates the on-device DSP pipeline, real-time FFT, and mechanical feature extraction before clinical production. |
| **`production_probe`** | ESP32-S3 Custom SoC | Dual ADXL355 (20-bit) | Production Contract | Dual-pickup synchronized sampling across the fixed $\Delta x = 40.0\text{ mm}$ baseline conforming to [hardware/BLE_SPECIFICATION.md](../hardware/BLE_SPECIFICATION.md). |

---

## 3. Quick Links

- [Hardware Specification](../hardware/README.md)
- [BLE Wire Contract Specification](../hardware/BLE_SPECIFICATION.md)
- [Mechanical Research Firmware Detailed Guide](thisulink-esp32s3-adxl345/arduino/thisulink_firmware/README.md)

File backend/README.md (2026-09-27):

# THISULINK™ Backend — Schema, RBAC & Event Engine

| | |
|---|---|
| **Document** | BE-SPEC-001 |
| **Platform** | PocketBase 0.22.21 (embedded SQLite, REST, SSE, JSVM hooks) |
| **Live** | **https://pb.thisulink.xyz** |
| **Infrastructure** | [INFRASTRUCTURE.md](INFRASTRUCTURE.md) |
| **Status** | Live in production — see §7 |

---

## 1. Role

One backend serves every client: authentication, role-based authorisation,
clinical record storage, file storage, realtime event delivery, and the
authoritative triage engine.

The triage engine runs **here**, not in the clients. Clients compute a
provisional tier so a field device works offline, but the server's computation
is the one that counts and the one that persists.

---

## 2. Collection architecture

```
                    ┌─────────────┐
                    │    users    │  auth · role · RBAC anchor
                    └──────┬──────┘
                           │ assigned_health_worker
                           ▼
                    ┌─────────────┐
                    │  patients   │  ABHA · demographics · active tier
                    └──────┬──────┘
                           │ patient_id
        ┌──────────────────┼──────────────────┬─────────────┐
        ▼                  ▼                  ▼             ▼
┌───────────────┐  ┌──────────────┐  ┌──────────────┐  ┌──────────┐
│ plantar_swe_  │  │  retinal_    │  │   vitals_    │  │ teleconsult
│   records     │  │  records     │  │   records    │  │ _sessions │
└───────┬───────┘  └──────┬───────┘  └──────┬───────┘  └──────────┘
        │                 │                 │
        └────────┬────────┴─────────────────┘
                 ▼  triggers triage recomputation
        ┌─────────────────┐        ┌───────────────┐
        │ triage_results  │───────►│ relay_alerts  │
        │ audit trail     │        │ escalation    │
        └─────────────────┘        └───────────────┘
```

### Canonical names

Earlier drafts used shorter names. **The live schema is authoritative**; both
frontends and the hook engine bind to it.

| Draft name | Live collection |
|---|---|
| `vitals` | `vitals_records` |
| `plantar_scans` | `plantar_swe_records` |
| `retinal_scans` | `retinal_records` |
| `triage_records` | `triage_results` |
| `consultations` | `teleconsult_sessions` |

Field names differ correspondingly — `sbp` → `systolic_bp`, `triage_color` →
`overall_tier`. These collections are live, populated and bound; renaming them
is a breaking migration with a data backfill, not a cosmetic edit.

---

## 3. Schema

### `users` — auth collection

| Field | Type | Notes |
|---|---|---|
| `email`, `password` | system | Email auth; 8-character minimum |
| `role` | select | `health_worker` \| `doctor` \| `patient` \| `admin` |
| `name` | text | |
| `phone` | text | |
| `assigned_phc` | text | Primary health centre |
| `district` | text | |
| `specialisation`, `hospital` | text | Clinician fields |

One auth collection with a role field, not one collection per role. Four roles
extend without a schema change, and a login is one request.

### `patients`

| Field | Type | Notes |
|---|---|---|
| `abha_id` | text | 14 digits, **unique index** |
| `name`, `age`, `gender`, `village` | | Demographics |
| `assigned_health_worker` | relation → `users` | Caseload anchor |
| `active_triage_status` | select | `green` \| `yellow` \| `orange` \| `red` |
| `current_cycle_day` | number | 1–6 |
| `diabetes_type` | text | |

**Indexes:** unique on `abha_id`; on `assigned_health_worker`; on
`active_triage_status` (the physician queue's primary filter).

`current_cycle_day` drives the entire reminder engine — which vital is due,
when the fundus photograph is taken, what a missed day means.

### `plantar_swe_records`

| Field | Type | Notes |
|---|---|---|
| `patient_id` | relation, cascade delete | |
| `operator_id` | relation → `users` | |
| `contact_force_n` | number | Stored as measured, including out-of-window |
| `shear_wave_speed_mps` | number | cₛ |
| `youngs_modulus_kpa` | number | E |
| `tissue_class` | select | `A_healthy` \| `B_early_glycation` \| `C_diabetic_neuropathy` |
| `thermal_asymmetry_delta_t` | number | °C |
| `resonance_peak_hz` | number | fₙ |
| `raw_packet_hex` | text | 73-byte frame as transmitted — audit trail |
| `cycle_day`, `measured_at` | | |

Contact force is stored even when invalid, so a reviewer can see *why* a scan
was rejected rather than finding it absent.

### `retinal_records`

| Field | Type | Notes |
|---|---|---|
| `patient_id`, `operator_id` | relation | |
| `image_file` | file | JPEG/PNG, 10 MB max |
| `eye_side` | select | `left` \| `right` |
| `predicted_dr_grade` | number | ICDR 0–4 |
| `referable_dr_prob` | number | 0.0–1.0 |
| `doctor_confirmed_grade` | number | **Nullable — absent means unreviewed** |
| `doctor_notes` | text | |

Nullability of `doctor_confirmed_grade` is load-bearing: it is how the sign-off
queue distinguishes unreviewed from reviewed-as-normal.

### `vitals_records`

| Field | Type |
|---|---|
| `patient_id`, `operator_id` | relation |
| `systolic_bp`, `diastolic_bp` | number, mmHg |
| `blood_glucose` | number, mg/dL |
| `reading_type` | select — `fasting` \| `post_prandial` \| `random` |
| `cycle_day`, `measured_at` | |

### `triage_results` — audit trail

| Field | Type |
|---|---|
| `patient_id` | relation |
| `overall_tier` | select — `green` \| `yellow` \| `orange` \| `red` |
| `reason_summary` | text — human-readable clinical justification |
| `computed_at` | date |

A row per computation, **including no-change computations**. The history must
show that a patient was assessed and found stable, not fall silent.

### `relay_alerts`

| Field | Type |
|---|---|
| `patient_id`, `health_worker_id` | relation |
| `status` | select — `pending` \| `acknowledged` \| `resolved` |
| `message` | text — tier and reason |

### `teleconsult_sessions`

| Field | Type |
|---|---|
| `patient_id`, `doctor_id` | relation |
| `room_name` | text |
| `status` | select — `scheduled` \| `in_progress` \| `completed` \| `cancelled` |
| `notes`, `prescription` | text |
| `started_at`, `ended_at` | date |

---

## 4. Zero-trust RBAC

### Rule model

| Constant | Expression |
|---|---|
| `CLINICIAN` | `@request.auth.role = "doctor" \|\| @request.auth.role = "admin"` |
| `STAFF` | `@request.auth.role = "health_worker" \|\| ... = "doctor" \|\| ... = "admin"` |
| `PATIENT_SCOPED` | `(CLINICIAN) \|\| (@request.auth.id = assigned_health_worker.id)` |

| Collection | list / view | create | update |
|---|---|---|---|
| `users` | self, or clinician | admin only | self, or clinician |
| `patients` | `PATIENT_SCOPED` | `STAFF` | `PATIENT_SCOPED` |
| `plantar_swe_records` | `STAFF` | `STAFF` | `CLINICIAN` |
| `retinal_records` | `STAFF` | `STAFF` | `CLINICIAN` |
| `vitals_records` | `STAFF` | `STAFF` | `CLINICIAN` |
| `triage_results` | `STAFF` | `STAFF` | `CLINICIAN` |
| `relay_alerts` | `STAFF` | `STAFF` | `STAFF` |
| `teleconsult_sessions` | `STAFF` | `CLINICIAN` | `CLINICIAN` |

A health worker sees their own caseload. Clinicians see the network. The
`patient` role appears in **no** allowlist and therefore reaches no clinical
collection.

---

### 4.1 Incident: cross-tenant PHI exposure

A real defect, found during production verification and fixed. It is recorded
here because the failure mode generalises.

#### What happened

PocketBase creates a default `users` auth collection on first run. The schema
migration guarded collection creation with an "already exists" check — correct
for every other collection, wrong for this one. The check passed, creation was
skipped, and the collection retained only PocketBase's own `name` and `avatar`
fields.

**The `role` field was never created.** No account had a role.

#### Why it was invisible

The original access rules used a negative exclusion:

```
   @request.auth.id != "" && @request.auth.role != "patient"
```

With `role` undefined, `role != "patient"` evaluates **true**. Every
authenticated account passed. Account provisioning succeeded and returned
identifiers; PocketBase silently discards unknown fields on create, so
`"role":"doctor"` was accepted and dropped without error.

#### Impact

Verified before the fix: the patient account could list **all 24 plantar
records, all 24 vitals records, all 4 retinal evaluations and all 8 triage
results** — every other patient's clinical data.

The defect surfaced only because the physician queue rendered empty: the
`patients` rule used a positive check (`role = "doctor"`), which correctly
failed closed. One collection failing closed is what exposed seven failing
open.

#### Fix

1. **Schema repaired** — `role` and the staff fields added; the migration now
   *extends* an existing `users` collection instead of skipping it.
2. **Rules rewritten as explicit allowlists.** An account whose role is
   missing, or carries a value added after the rules were written, is now
   **denied by construction**.

```
   ✗ negative exclusion              ✓ explicit allowlist
   role != "patient"                 role = "health_worker"
                                  || role = "doctor"
   unknown role → ADMITTED        || role = "admin"
                                     unknown role → DENIED
```

#### Verified after the fix

| Account | patients | plantar | vitals | retinal |
|---|---|---|---|---|
| `doctor` | 4 | 24 | 24 | 4 |
| `health_worker` | 4 | 24 | 24 | 4 |
| **`patient`** | **0** | **0** | **0** | **0** |

#### Generalisation

An exclusion rule fails **open** when the field it tests is absent. An
allowlist fails **closed**. In any system holding protected health
information, authorisation must be expressed as an allowlist — not because it
reads better, but because the two behave oppositely under exactly the
condition nobody tests for.

---

## 5. Realtime event engine

### Triage recomputation

```
   record created in plantar_swe_records | vitals_records | retinal_records
   ── or ── retinal_records updated (physician sign-off)
                       │
                       ▼
   load the patient's LATEST record of EACH modality
                       │
                       ▼
   compute tier (first match wins, most severe first)
                       │
        ┌──────────────┼──────────────────┐
        ▼              ▼                  ▼
   write audit    update patient     if ENTERING red/orange
   row (always)   tier if changed    and no alert pending:
                       │              raise relay_alert
                       ▼
                 SSE event → Specialist Workstation queue
```

### Tier rules

| Tier | Condition — first match wins |
|---|---|
| 🔴 RED | Tissue class C, **or** P(referable) ≥ 0.50 with grade ≥ 3, **or** glucose > 400 mg/dL |
| 🟠 ORANGE | Class B with ΔT ≥ 2.2 °C, **or** P(referable) ≥ 0.50, **or** glucose > 300 |
| 🟡 YELLOW | Class B, **or** ΔT ≥ 2.2 °C, **or** grade ≥ 2, **or** glucose > 180 |
| 🟢 GREEN | None of the above |

### Engine properties

| Property | Rationale |
|---|---|
| Computed from the latest of **each** modality | A glucose reading hours after a foot scan must not discard that scan |
| `doctor_confirmed_grade` supersedes prediction, **including 0** | A physician's "no retinopathy" is never reverted by null-coalescing |
| Audit row on every computation | History shows assessment, not silence |
| Alert only on **entering** a priority tier, and only if none pending | A patient who remains unwell must not bury their health worker |
| Failure never rolls back the clinical record | The reading matters; a tier can be recomputed |

### Manual recomputation

`POST /api/thisulink/retriage` — admin authenticated. Recomputes every patient
and reports `{recomputed, total, failures}`. Used after a rule change or to
backfill.

---

### 5.1 Incident: silent hook failure

A second real defect, also found in production verification.

**PocketBase executes every JSVM hook handler in its own isolated context.**
Declarations at the top level of a hook file are not visible inside the handler
body — referencing one throws `ReferenceError` at request time, not at load.

The handlers were registered correctly and called on schedule, but every
invocation threw on its first line. Because the hook catches its own errors to
protect the clinical write, records saved normally, the API returned 200, and
`triage_results` stayed empty. The only evidence was a line in the service
journal.

**Fix:** the engine is a separate module, `require()`d from **inside** each
handler body rather than closed over.

**Generalisation:** a hook that swallows its own errors to protect a write must
be monitored on its *output*, not its status code. The check that caught this
was noticing that `triage_results` had zero rows after seeding data that must
produce eight.

---

## 6. API surface

| Operation | Endpoint |
|---|---|
| Health | `GET /api/health` |
| Authenticate | `POST /api/collections/users/auth-with-password` |
| Refresh | `POST /api/collections/users/auth-refresh` |
| Records | `GET|POST|PATCH /api/collections/{name}/records` |
| Files | `GET /api/files/{collection}/{id}/{filename}` |
| Realtime | `GET /api/realtime` (SSE) |
| Recompute triage | `POST /api/thisulink/retriage` (admin) |
| **Administration console** | `/_/` — **mesh only; 404 at the public edge** |

### Query safety

Filter strings are **not parameterised**. Every user-supplied value is escaped
before interpolation — backslash and double-quote — in all clients. A quote
that terminates a filter literal is an authorisation bypass, not a syntax
error.

---

## 7. Implementation status

| Component | Status |
|---|---|
| Deployment | **Live at https://pb.thisulink.xyz** |
| Eight collections, indexes, relations | **Live** |
| RBAC allowlists | **Live and verified** — patient isolation confirmed |
| Triage engine | **Live and verified end to end** |
| Relay escalation | **Verified** — alert raised on tier entry with clinical reason |
| Realtime SSE | Live |
| Manual recompute endpoint | Live |
| Seeded clinical dataset | 4 accounts · 4 patients · 24 plantar · 24 vitals · 4 retinal |
| Administration console exposure | **404 publicly, mesh-only** |
| **Tele-consultation token service** | **Not deployed** |
| **Automated backups** | **Not configured** — see INFRASTRUCTURE.md |

### Verified tier assignment

| Patient | Tissue | ΔT | Glucose | ICDR | Tier |
|---|---|---|---|---|---|
| Meena Devi | C | 2.7 °C | 262 | 4 | 🔴 RED |
| Saravanan S | B | 2.4 °C | 216 | 2 | 🟠 ORANGE |
| Ravi Kumar | B | 1.9 °C | 168 | 1 | 🟡 YELLOW |
| Arjun Prakash | A | 1.2 °C | 138 | 0 | 🟢 GREEN |

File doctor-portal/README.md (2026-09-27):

# THISULINK™ Specialist Clinical Workstation

| | |
|---|---|
| **Document** | SW-DOC-001 |
| **User** | Specialist, endocrinologist, medical officer |
| **Roles** | `doctor`, `admin` |
| **Platform** | Web (Flutter) |
| **Live** | **https://thisulink.xyz** · **https://doctor.thisulink.xyz** |
| **Source** | `doctor_portal/` (client build artefact) |
| **Status** | Live in production — see §8 |

---

## 1. Purpose

The workstation is where clinical judgement is applied. Field encounters arrive
continuously, already stratified by the triage engine; the physician's scarce
attention is directed at the cases that warrant it, with the complete evidence
for each in one place.

Its design goal is a short path from *a red case arrived* to *a decision was
recorded*.

### Access boundary

Entry requires `doctor` or `admin`. An authenticated account with any other
role has its session cleared and is refused — health workers use the Clinical
Diagnostic Suite, patients the Health Companion. Authorisation is enforced at
the backend by explicit allowlist, not by hiding routes in the client.

---

## 2. Physician queue

### Realtime delivery

```
   health worker saves an encounter
              │
              ▼
   PocketBase hook recomputes triage
              │
              ▼
   patients.active_triage_status updated
   triage_results audit row written
              │
              ▼
   PocketBase realtime event (SSE)
              │
              ▼
   ┌────────────────────────────────────────┐
   │  WORKSTATION QUEUE                     │
   │  • row inserted in priority position   │
   │  • tier counters increment             │
   │  • audible chime on RED / ORANGE       │
   │  • banner: "New critical encounter"    │
   └────────────────────────────────────────┘
```

Delivery is Server-Sent Events over the same gateway as the REST API. No
polling; the queue updates without a refresh.

> **Operational note.** The SSE stream is long-lived. Any proxy between client
> and backend must not buffer it. A buffered stream fails invisibly — the queue
> simply stops updating while every health check reports normal. The production
> reverse proxy disables buffering on this route specifically.

### Ordering

Strictly by clinical risk, never by arrival time:

| Order | Tier | Meaning |
|---|---|---|
| 1 | 🔴 **RED** | Critical — immediate referral |
| 2 | 🟠 **ORANGE** | Priority — escalate |
| 3 | 🟡 **YELLOW** | Moderate — monitor, recheck next cycle |
| 4 | 🟢 **GREEN** | Stable — no action |

A chronological queue buries a critical case behind twenty routine ones. The
tier filter row carries live counts, so the size of each tier is visible before
any case is opened.

### Search

| Field | Behaviour |
|---|---|
| ABHA ID | Exact or partial |
| Patient name | Substring |
| Village | Substring, for outbreak or camp review |

Search values are escaped before interpolation — backend filter strings are not
parameterised.

---

## 3. Encounter review

### Patient dossier

Demographics, ABHA identifier, assigned health worker, current cycle day, and
full longitudinal history across every modality.

### Plantar biomechanics viewer

| Panel | Content |
|---|---|
| **Interlock banner** | Contact force with the 1.40–1.60 N window; out-of-window capture flagged prominently |
| **Metrics** | cₛ, Young's modulus E, tissue class, ΔT |
| **Time domain** | Dual-pickup acceleration overlay, phase offset visible |
| **Frequency domain** | FFT across the 10–300 Hz sweep with resonance marker fₙ |
| **Thermal** | Contralateral asymmetry gauges against the 2.2 °C threshold |
| **Raw frame** | Hex dump of the 73-byte packet as transmitted |

The interlock banner leads because it determines whether the rest of the panel
means anything. A scan captured outside the force window is not a noisy
measurement — it is a measurement of a different mechanical state, and the
physician must see that before reading the modulus.

The raw frame panel is the audit trail. If a reading is ever disputed, this is
what the probe actually sent.

### Retinal viewer

| Element | Behaviour |
|---|---|
| Presentation | Both eyes side by side, laterality labelled |
| Navigation | Zoom 1×–6×, pan |
| AI output | ICDR grade with P(referable) against the 0.50 threshold |
| **Override** | Physician records `doctor_confirmed_grade` |
| Notes | Free-text clinical annotation |

**A confirmed grade supersedes the prediction, including grade 0.** A physician
recording "no retinopathy" over a model's grade 3 is a clinical decision and is
never silently reverted. This is enforced in the triage engine and covered by
its tests.

### Longitudinal vitals

Blood pressure and glucose over time, with threshold bands drawn. Axes always
extend past the clinical threshold, so a reference line never falls off a chart
whose data sits entirely below it.

---

## 4. Clinical actions

### Tele-consultation

```
   [ Start consultation ]
            │
            ▼
   POST /api/livekit/token   ← server-side minting, authenticated session
            │
            ▼
   join room — patient, physician, optionally the health worker
            │
            ▼
   ┌─────────────────────────┬──────────────────────────┐
   │  Live vitals, history   │   HD video               │
   │  and encounter evidence │                          │
   └─────────────────────────┴──────────────────────────┘
            │
            ▼
   notes · prescription · diet plan recorded against the consultation
```

The token is minted by the server. The signing secret never reaches a browser —
a secret shipped in a web bundle is a published secret, and these rooms carry
clinical consultations.

### Digital prescription

| Element | Behaviour |
|---|---|
| Composition | Structured medication formulary |
| Signature | Physician cryptographic signature |
| Output | Signed PDF, attached to the consultation |
| Mutability | Immutable once signed; amendment creates a new version |

### Dietary plan approval

The AI-generated nutrition plan is presented for review. The physician
approves, modifies, or rejects it; only an approved, signed plan becomes the
boundary within which the patient's dietary assistant is permitted to answer.

This sign-off is the gate described in
[patient-app/](../software/patient-app/README.md) §4. Without it the assistant
has no approved plan to be constrained by.

---

## 5. Closed-loop lifecycle

```
  HEALTH WORKER                 BACKEND                    PHYSICIAN
       │                           │                            │
       │ capture encounter         │                            │
       ├──────────────────────────►│                            │
       │                           │ recompute triage           │
       │                           │ write audit row            │
       │                           │ update patient tier         │
       │                           │                            │
       │                           │ if entering RED/ORANGE:    │
       │                           │   raise relay alert        │
       │                           │                            │
       │                           │ SSE event ────────────────►│
       │                           │                       queue updates
       │                           │                       chime + banner
       │                           │                            │
       │                           │◄── open encounter ─────────┤
       │                           │    review evidence         │
       │                           │                            │
       │                           │◄── confirm/override grade ─┤
       │                           │ recompute triage           │
       │                           │                            │
       │◄─── consultation invite ──┼────────────────────────────┤
       │     (health worker joins) │                            │
       │                           │◄── prescription signed ────┤
       │                           │◄── diet plan approved ─────┤
       │                           │                            │
       │◄── alert acknowledged ────┤                            │
       │    follow-up scheduled    │                            │
```

Every transition is recorded. `triage_results` accumulates one row per
computation — including no-change ones — so the record shows the patient was
assessed and found stable rather than going silent.

---

## 6. Interface conventions

| Convention | Rationale |
|---|---|
| Tier colours are reserved | Amber and crimson appear only for clinical severity, never decoratively |
| Loading states shimmer | Distinguishes "loading" from "empty" — an empty queue and an unloaded queue must never look alike |
| Errors are actionable | "Device disconnected. Check Bluetooth pairing." — states what to do |
| Intended-use notice is persistent | Present on every page; the accountability chain is never ambiguous |
| Desktop-first, responsive | Laid out for a workstation, collapses below 1000 px |

---

## 7. Operating modes

| Mode | Endpoint |
|---|---|
| Production gateway | `https://pb.thisulink.xyz` |
| **Field camp** | Local backend, selected at runtime |

The login screen exposes a backend indicator, a reachability test, and a
field-camp toggle. A clinic running its own backend on a local machine with no
internet switches without a rebuild or a configuration file edit.

---

## 8. Implementation status

| Component | Status |
|---|---|
| Deployment | **Live at https://thisulink.xyz and https://doctor.thisulink.xyz** |
| Authentication, role gate, session handling | **Live and verified** |
| Triage queue, tier filters, live counts | Implemented |
| Realtime SSE subscription | Implemented; buffering disabled at the proxy |
| ABHA / name / village search | Implemented, injection-escaped |
| Plantar waveform, FFT, thermal, raw-frame panels | Implemented |
| Retinal viewer, zoom/pan, override, sign-off | Implemented |
| Longitudinal vitals charts | Implemented |
| Signed report generation | Implemented |
| Static analysis | Clean |
| **Tele-consultation** | **Blocked — token service not deployed** |
| **Structured formulary and cryptographic signature** | **Not implemented** |
| **Dietary plan approval flow** | **Not implemented** |
| **Automated tests** | **None** |

### Honest gaps

**Tele-consultation cannot start.** The `POST /api/livekit/token` endpoint is
not deployed, so session creation reports that no join token was returned.
Every other function is unaffected.

**The workstation has no test suite.** The field client has 63 tests; this
application has none. The triage logic it displays is tested in the shared
domain layer, but its own presentation and state handling are verified only by
inspection and by live use against production data.

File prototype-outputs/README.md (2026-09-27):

# THISULINK™ — Prototype Outputs (Screen-by-Screen Verification Guide)

This directory documents the verified prototype outputs and screenshots across the complete THISULINK ecosystem: Doctor Portal (Web), Health Worker Clinical Diagnostic Suite (Windows/Desktop), and Patient Health Companion (Mobile). To browse them as an interactive visual gallery, open [`index.html`](index.html) in your browser.

## Contents

- [System overview](#system-overview)
- [How these screenshots were made](#how-these-screenshots-were-made)
- [1. Doctor Portal (web)](#1-doctor-portal-web)
  - [1.1 Sign in](#11-sign-in)
  - [1.2 Complete your account (first sign-in)](#12-complete-your-account-first-sign-in)
  - [1.3 Triage command centre](#13-triage-command-centre)
  - [1.4 Triage queue filtered to one tier](#14-triage-queue-filtered-to-one-tier)
  - [1.5 Retinal fundus review](#15-retinal-fundus-review)
  - [1.6 Clinician sign-off of a DR grade](#16-clinician-sign-off-of-a-dr-grade)
  - [1.7 Tele-consult studio](#17-tele-consult-studio)
  - [1.8 AI diet plan: released](#18-ai-diet-plan-released)
  - [1.9 AI diet plan: flagged for review](#19-ai-diet-plan-flagged-for-review)
  - [1.10 Notifications](#110-notifications)
  - [1.11 e-Prescription: add medication](#111-e-prescription-add-medication)
  - [1.12 Consultation notes, prescription and signed report](#112-consultation-notes-prescription-and-signed-report)
  - [1.13 Account menu](#113-account-menu)
  - [1.14 Signed consultation report](#114-signed-consultation-report)
- [2. Health Worker app (Clinical Diagnostic Suite)](#2-health-worker-app-clinical-diagnostic-suite)
  - [2.1 Sign in](#21-sign-in)
  - [2.2 Complete your account](#22-complete-your-account)
  - [2.3 Patient registry (today's caseload)](#23-patient-registry-todays-caseload)
  - [2.4 Add new patient](#24-add-new-patient)
  - [2.5 Create patient app login](#25-create-patient-app-login)
  - [2.6 One-time password](#26-one-time-password)
  - [2.7 Approve an app sign-up](#27-approve-an-app-sign-up)
  - [2.8 Screening session](#28-screening-session)
  - [2.9 Foot scan with the probe](#29-foot-scan-with-the-probe)
  - [2.10 Glucose, blood pressure and fundus import](#210-glucose-blood-pressure-and-fundus-import)
  - [2.11 Patient history](#211-patient-history)
  - [2.12 Profile](#212-profile)
  - [2.13 Settings (probe, reminders, sync)](#213-settings-probe-reminders-sync)
- [3. Patient app (Health Companion)](#3-patient-app-health-companion)
  - [3.1 Sign in](#31-sign-in)
  - [3.2 Create your account](#32-create-your-account)
  - [3.3 Waiting for approval](#33-waiting-for-approval)
  - [3.4 First sign-in: details and new password](#34-first-sign-in-details-and-new-password)
  - [3.5 Home](#35-home)
  - [3.6 Readings and trends](#36-readings-and-trends)
  - [3.7 Record a reading](#37-record-a-reading)
  - [3.8 Consultations](#38-consultations)
  - [3.9 Diet plan](#39-diet-plan)
  - [3.10 Profile](#310-profile)

---

## System overview

THISULINK screens people with diabetes for complications in rural areas, using a 6-day monitoring cycle. It has three apps that share one backend:

| App | Who uses it | Platform | What it is for |
|---|---|---|---|
| **Doctor Portal** | Doctors and administrators | Web (Flutter web) | Works through the triage queue, reviews retinal images and confirms their grades, runs video tele-consultations, writes e-prescriptions and exports a signed PDF report. |
| **Health Worker app** (Clinical Diagnostic Suite) | Frontline health workers | Windows desktop and Android | Enrols patients and runs the daily screening session: foot scan with the THISULINK probe over Bluetooth, glucose and BP, and a fundus photo on days 1 and 4. It also sets up patients' app access. Sessions are saved on the device first and synced later, so it keeps working offline. |
| **Patient app** (Health Companion) | Patients | Android and iOS | Lets patients log glucose and BP, see their trends, join video consultations, read their prescriptions and follow their AI diet plan. |

**Backend: PocketBase.** A single PocketBase server stores every record: users (with a `role`), patients, vitals, foot-scan, retinal, triage results, tele-consult sessions, care plans and doctor notifications. Server hooks handle the rest:

- **Triage.** Each new reading recomputes the patient's tier from their latest reading of each type. The tiers are Green (normal), Yellow (moderate), Orange (high risk) and Red (emergency). When a patient becomes Orange or Red, the hook raises an alert for their health worker.
- **Accounts.** Health workers can create a mobile-number login for a patient, which comes with a one-time password. They can also approve a patient's self sign-up by matching the email address.
- **AI diet plans.** When a doctor completes a tele-consultation with notes, a care plan is queued. A background job asks an LLM (Groq) to turn the doctor's remarks into a structured one-day plan. A second model call reviews the plan, and fixed rule checks run alongside it (the doctor's restrictions are respected, no high-sugar foods, targets in sensible ranges). Together these produce a **quality score**. At 92 % or above the plan is **released**. Below that it is **flagged**: the patient still sees it, and the doctor gets a notification asking them to review it or press **Regenerate**.
- **Video.** Tele-consultations use **LiveKit**. PocketBase issues the room token only to the doctor, health worker and patient on that consultation.

## How these screenshots were made

- All data is **fictional** and was loaded into a **local test PocketBase**. No production server was contacted. This is why some screens show a server address of `http://127.0.0.1:8099`.
- The fundus images are **synthetic illustrations**, not real retinal photographs.
- The AI diet plans came from the real care-plan pipeline (queue → generate → review → score → release or flag). A local stand-in for the LLM supplied the model replies.
- The health-worker foot scan used the app's built-in **simulated probe stream**. That mode deliberately blocks **Submit session**, so no synthetic reading can be saved against a patient.
- Live video could not be shown because the local server has no LiveKit keys. The studio is shown before a call starts.
- The signed PDF report (1.14) was built from the Doctor Portal's built-in demo data in a Flutter test and rendered to an image.
- Doctor Portal and Patient app were captured from their web builds in a headless browser. The Patient app used a phone-sized viewport. The Health Worker app was captured from its Windows desktop build.

---

## 1. Doctor Portal (web)

Used by: **doctors** (and administrators). Signed in here as *Dr. Lukesh M*.

### 1.1 Sign in

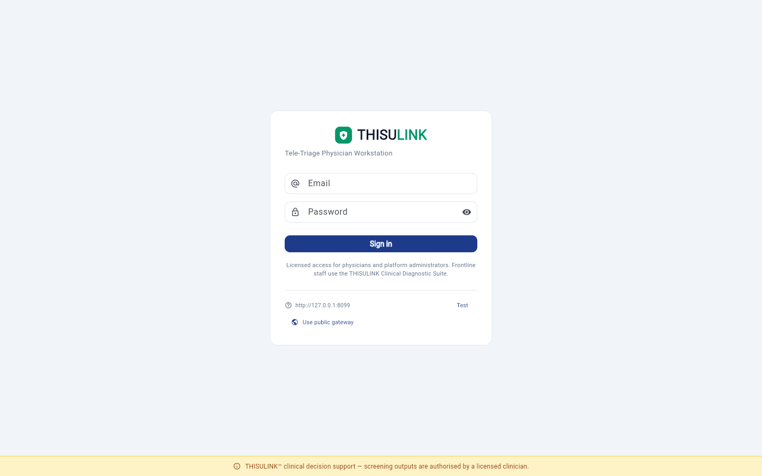
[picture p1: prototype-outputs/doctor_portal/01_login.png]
Doctor Portal sign-in


The entry point to the physician workstation.

- **Email / Password.** Staff accounts are created by an administrator. Only accounts with the `doctor` or `admin` role can sign in here. Health workers are told to use the mobile/desktop app instead.
- **Server row (bottom).** Shows the server the portal is using and has a **Test** button that checks it. On a portal served over plain `http` there is also a switch between the public gateway and a LAN server, so a field camp without internet can use a PocketBase on the local network.
- **Disclaimer bar.** Present on every page: screening outputs are decision support and must be authorised by a licensed clinician.

### 1.2 Complete your account (first sign-in)

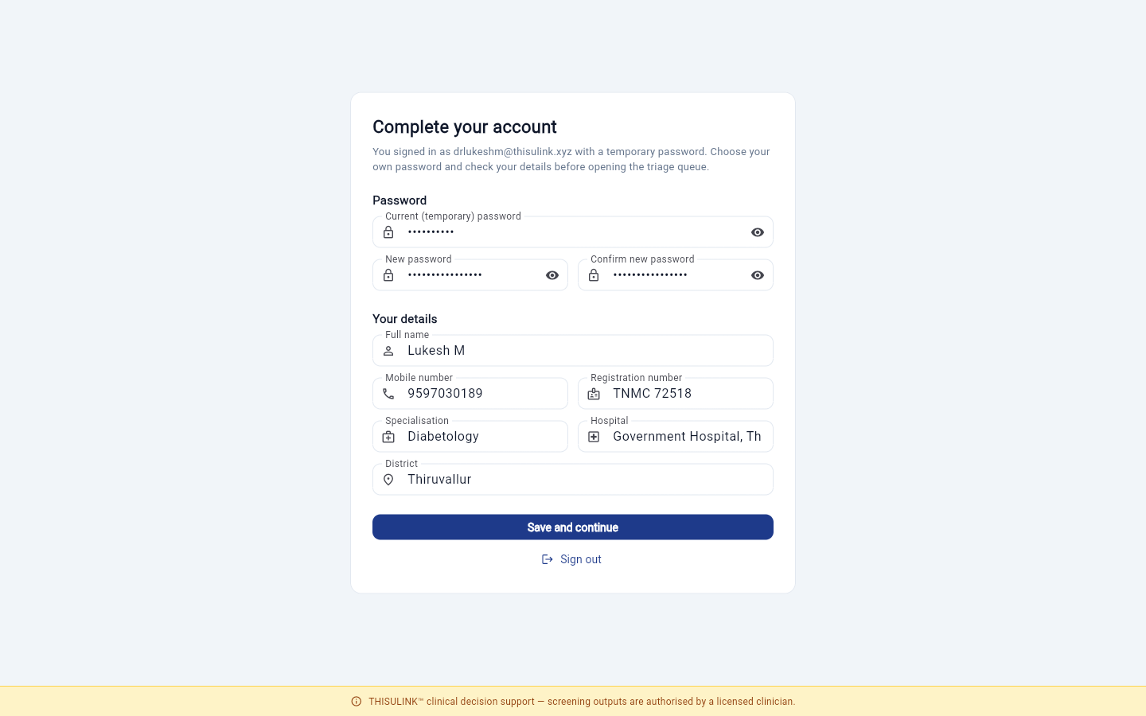
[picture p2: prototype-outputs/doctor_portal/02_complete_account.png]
Complete your account


Shown at `#/welcome` the first time a doctor signs in with the temporary password an administrator gave them. Every other page stays locked until this is done.

- **Password.** Enter the temporary password, then choose and confirm a new one (at least 8 characters, and different from the temporary one).
- **Your details.** Full name, mobile number, medical **registration number** (printed on signed reports), specialisation, hospital and district. The form is pre-filled from what the administrator entered.
- **Save and continue** saves everything and opens the triage queue. **Sign out** leaves without saving.

### 1.3 Triage command centre

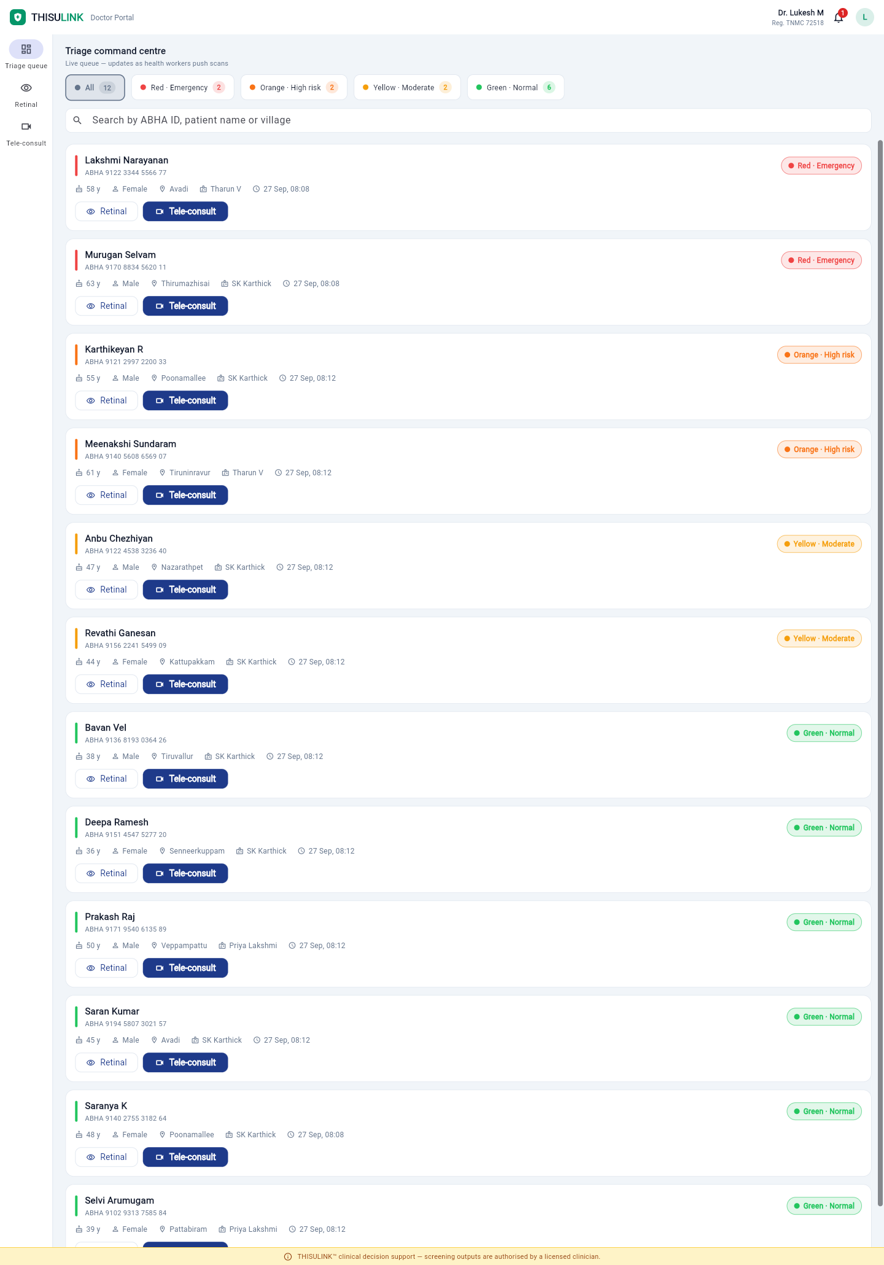
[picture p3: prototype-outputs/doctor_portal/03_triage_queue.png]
Triage queue


The doctor's home screen: a live queue of every patient, ordered by urgency.

- **Top bar.** The doctor's name and registration number, a **notification bell** with an unread count (see 1.10), and the **account** avatar (see 1.13).
- **Left rail.** **Triage queue**, **Retinal** (fundus review) and **Tele-consult** (the studio).
- **Tier filter chips.** *All*, *Red · Emergency*, *Orange · High risk*, *Yellow · Moderate* and *Green · Normal*, each with its count.
- **Search.** Search by ABHA ID, patient name or village.
- **Patient cards.** Each card has a colour bar for the tier and shows the name, ABHA number, age, gender, village, assigned health worker and last update. Red patients are always listed first. **Retinal** opens the fundus review and **Tele-consult** opens the studio for that patient. Clicking the card itself opens the retinal review.
- The queue updates in real time as health workers upload readings.

### 1.4 Triage queue filtered to one tier

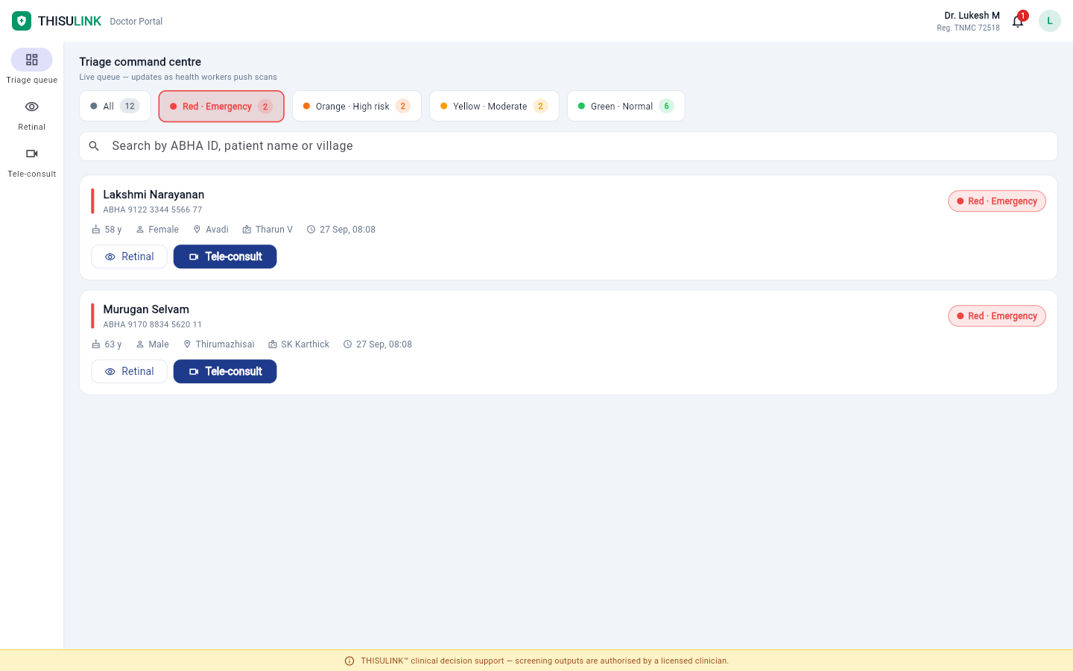
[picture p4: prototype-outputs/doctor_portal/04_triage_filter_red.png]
Red tier only


The same queue with only the **Red · Emergency** chip selected, so the doctor sees just the emergencies. In this example, one patient is Red because of diabetic neuropathy found on the foot scan (tissue class C). The other is Red because of referable diabetic retinopathy at grade 3.

### 1.5 Retinal fundus review

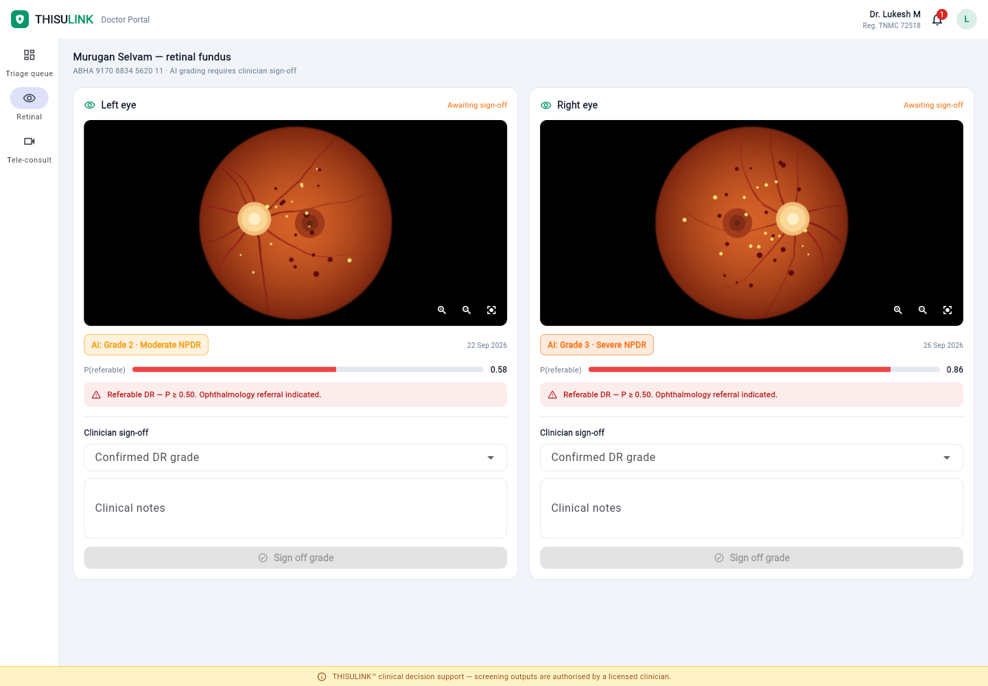
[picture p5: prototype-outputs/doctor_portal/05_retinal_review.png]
Retinal review


Side-by-side review of the left and right fundus photos taken by the health worker.

- **Image viewer.** Zoom in, zoom out and reset the view. The image can also be dragged or pinched.
- **AI grade chip.** The on-device/server model's ICDR diabetic retinopathy grade (0 = no DR … 4 = proliferative DR) and the date of the capture.
- **P(referable) bar.** The model's probability that the DR is referable. At 0.50 or above a red banner appears: *Referable DR — ophthalmology referral indicated*.
- **Awaiting sign-off.** Shown until a clinician confirms the grade. The AI grade is never treated as final on its own.

### 1.6 Clinician sign-off of a DR grade

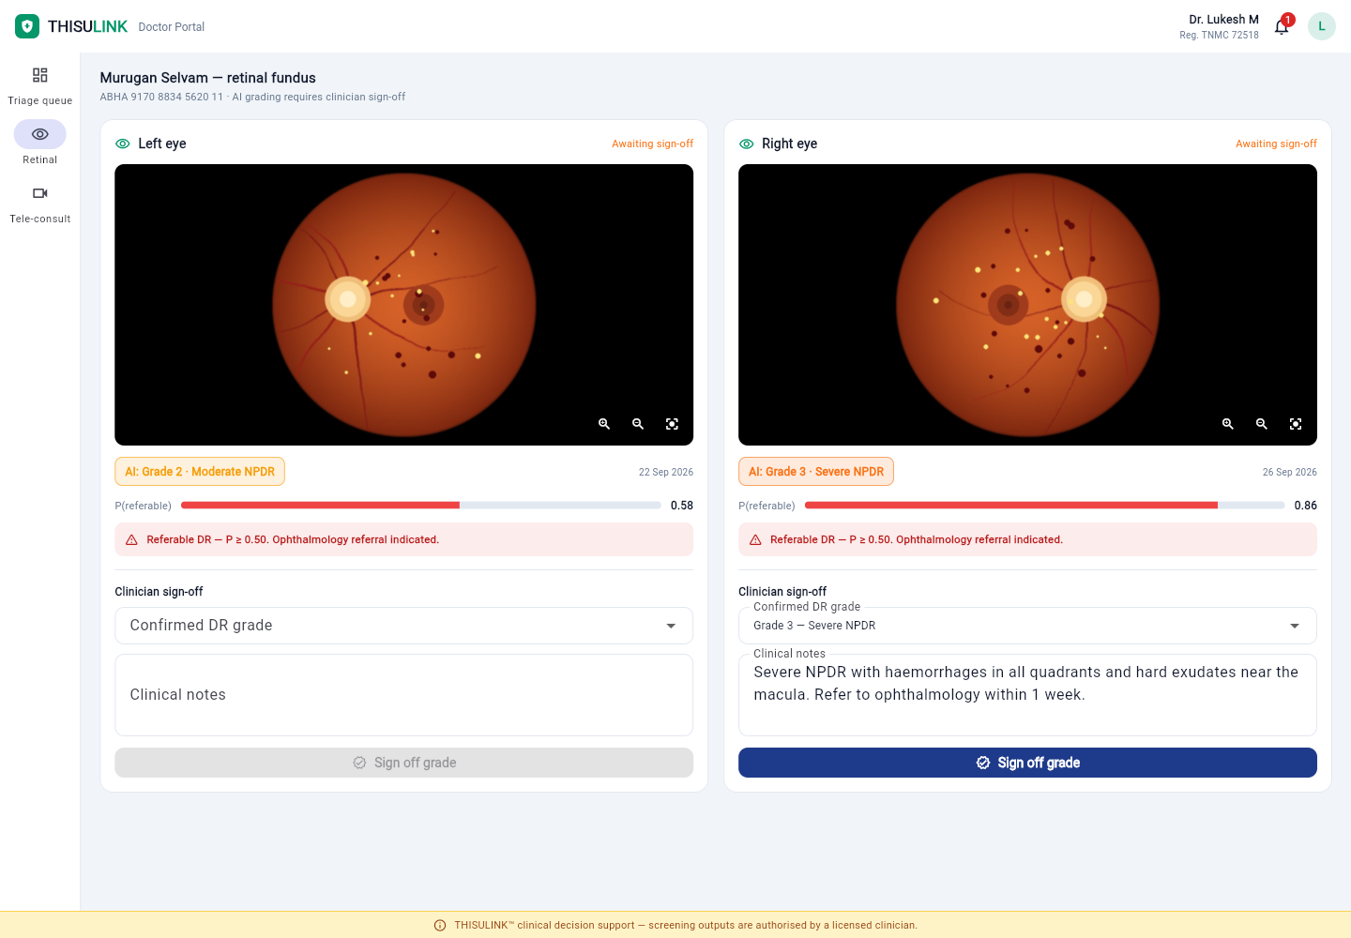
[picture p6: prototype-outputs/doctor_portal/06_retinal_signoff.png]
Sign-off form filled

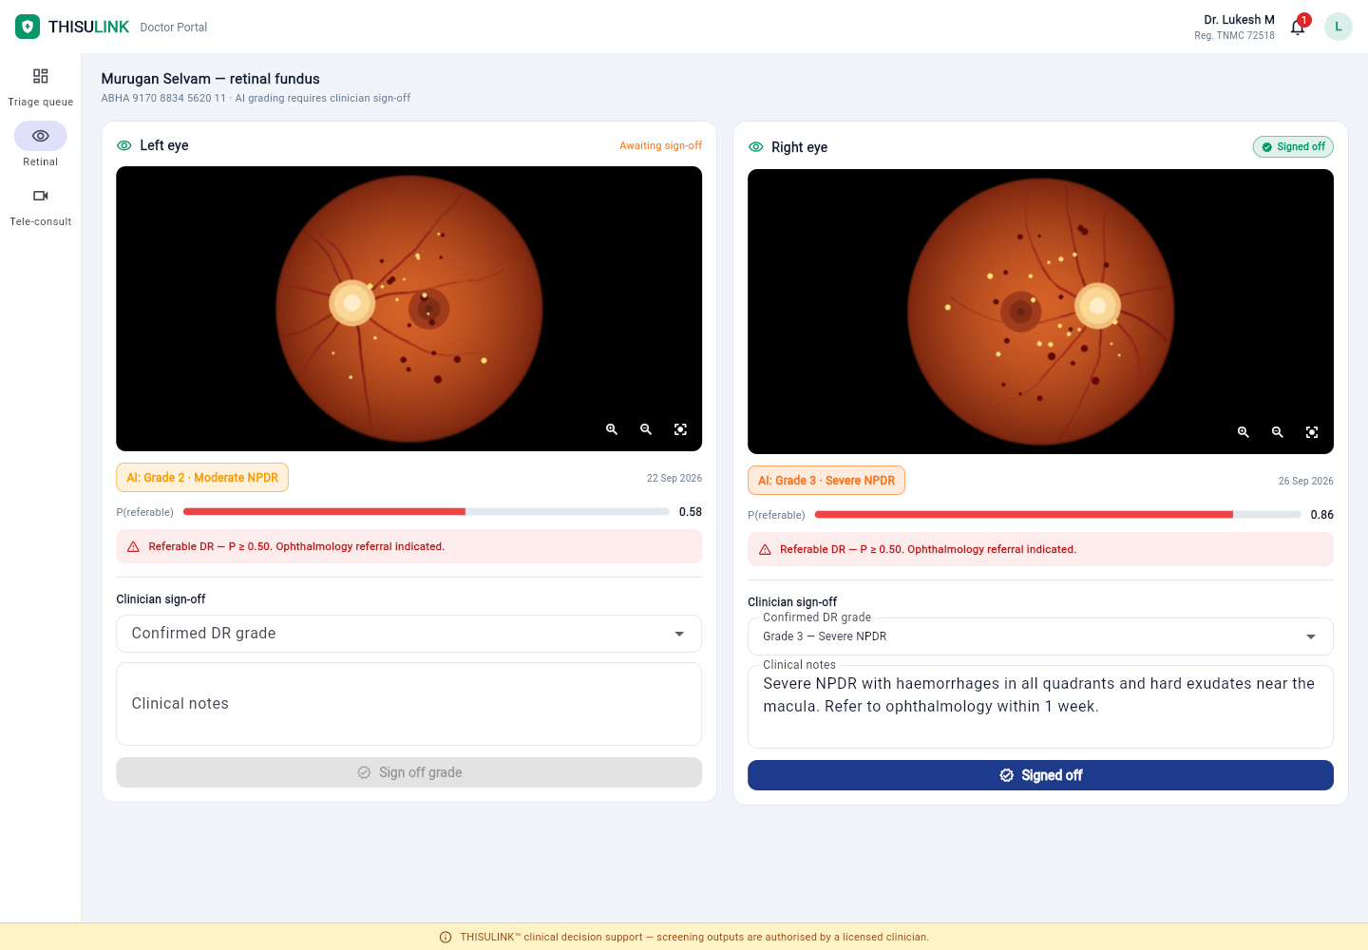
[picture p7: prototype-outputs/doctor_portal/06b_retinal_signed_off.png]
Signed off


- **Confirmed DR grade.** The doctor either confirms the AI grade or picks a different one from the drop-down.
- **Clinical notes.** Free-text findings and the follow-up plan.
- **Sign off grade.** Saves the confirmed grade, the doctor's name and the time. The eye's status then changes to **Signed off**. From this point triage uses the doctor's grade instead of the AI's.

### 1.7 Tele-consult studio

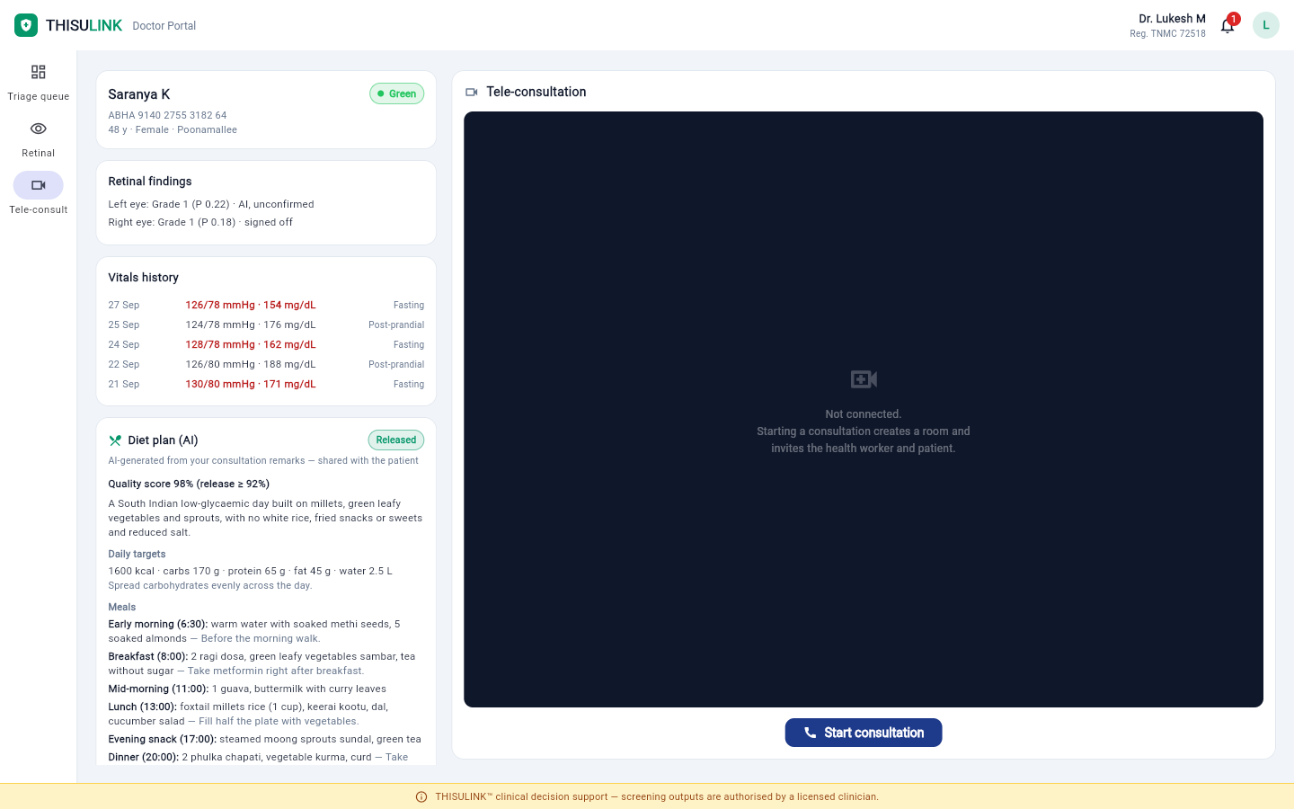
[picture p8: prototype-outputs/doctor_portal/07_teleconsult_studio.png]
Tele-consult studio


The studio has two panes. The left pane holds the patient's clinical context and the right pane holds the video call.

- **Patient card.** Name, triage tier, ABHA number, age, gender and village.
- **Retinal findings.** A short summary per eye: grade, probability and whether a doctor has signed it off.
- **Vitals history.** The last five readings (BP and glucose), with out-of-range values in red and the reading type (fasting or post-prandial).
- **Video pane.** **Start consultation** creates or reuses a LiveKit room and invites the health worker and the patient. The patient app then shows a *Join* button. While the call is running there are camera, microphone and **End** controls. Ending the call saves the notes and prescription and marks the consultation *completed*, which triggers the AI diet plan.

### 1.8 AI diet plan: released

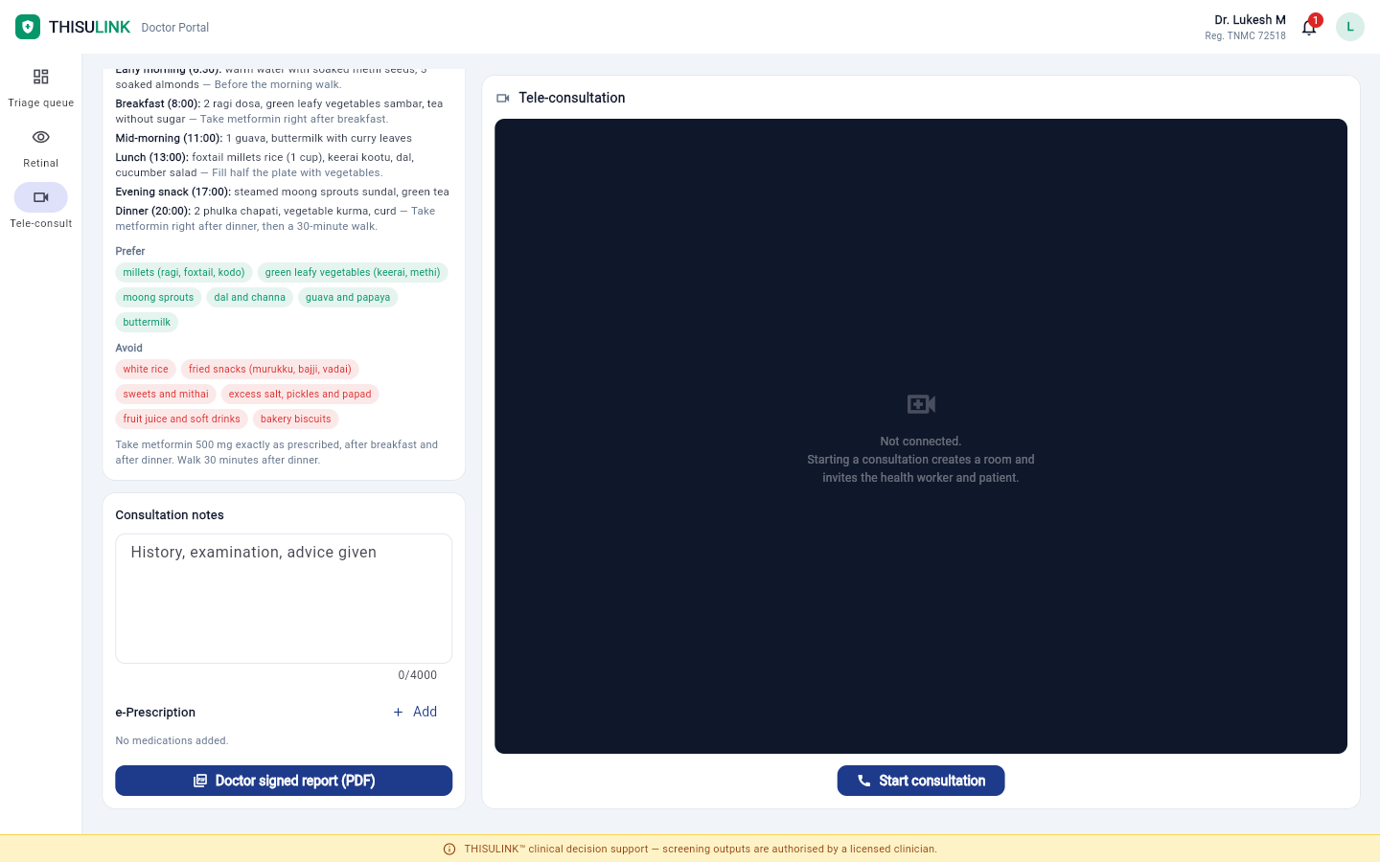
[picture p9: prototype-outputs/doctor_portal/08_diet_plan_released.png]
Released diet plan


Further down the left pane is the **Diet plan (AI)** card for the patient's latest completed consultation.

- **Status chip.** *Generating…*, *Released*, *Flagged* or *Failed*.
- **Quality score.** The combined rule and reviewer score, compared with the 92 % release threshold (98 % here).
- **Plan body.** A summary, daily targets (kcal, carbohydrate, protein, fat, water), meals with times and notes, and **Prefer** (green) and **Avoid** (red) food chips. This is the same plan the patient sees.

### 1.9 AI diet plan: flagged for review

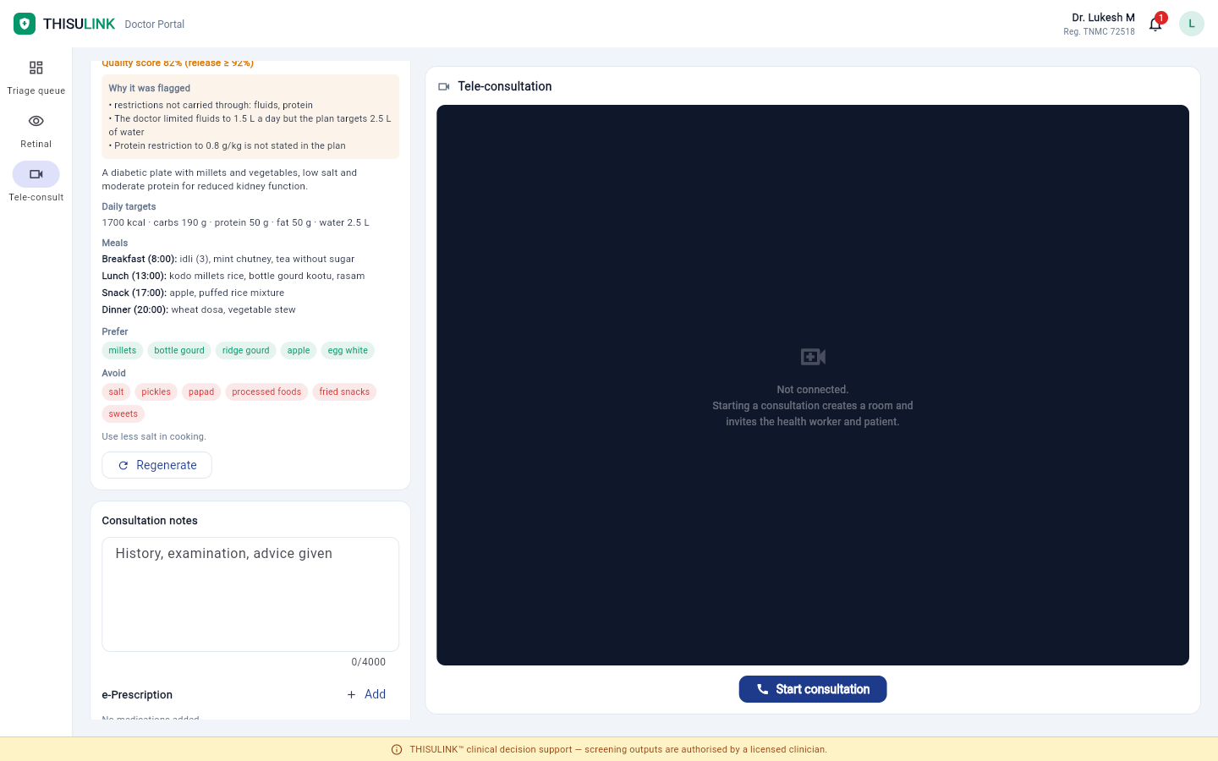
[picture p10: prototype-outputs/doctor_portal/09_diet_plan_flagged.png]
Flagged diet plan


A plan that scored below 92 % (82 % here).

- **Why it was flagged.** The rule-check problems and the reviewer's issues. Here the plan ignored the doctor's fluid and protein limits.
- **Regenerate.** Queues a new plan built from the same consultation remarks. The newest plan replaces the older ones for the patient.
- The patient can still see a flagged plan, but the doctor is notified (see 1.10).

### 1.10 Notifications

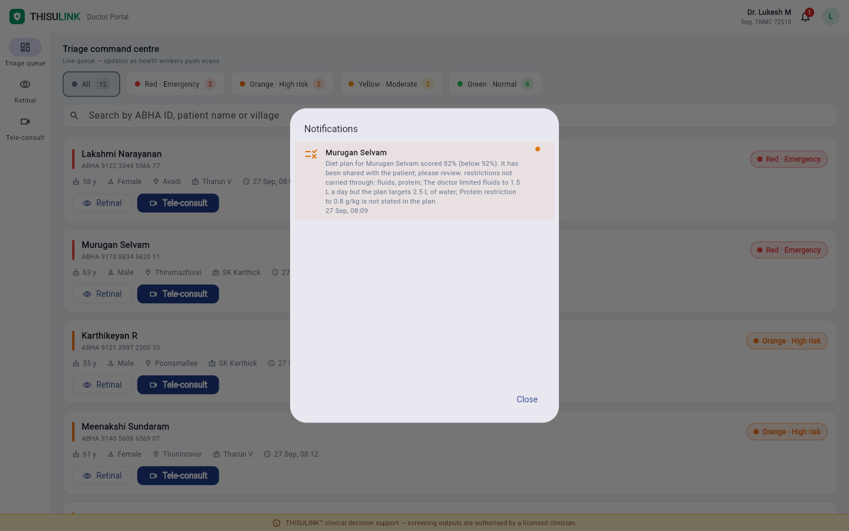
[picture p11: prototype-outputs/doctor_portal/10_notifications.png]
Notifications dialog


Opened from the bell in the top bar. It lists diet-plan events for this doctor's patients: *low accuracy* (flagged) and *failed* (the plan could not be generated after retries). Each entry shows the patient, the reason and the time. An orange dot marks an unread entry, and clicking an entry marks it read.

### 1.11 e-Prescription: add medication

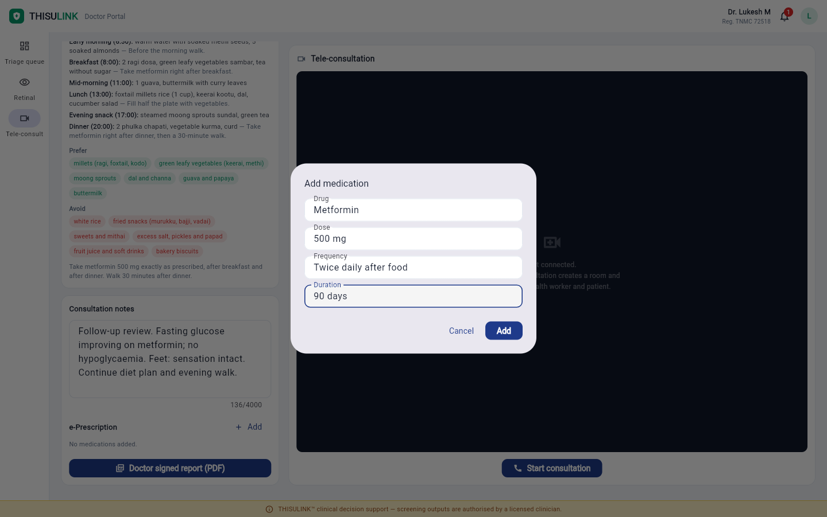
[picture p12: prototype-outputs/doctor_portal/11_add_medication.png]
Add medication


Opened with **+ Add** under *e-Prescription*. Fields: **Drug**, **Dose**, **Frequency** and **Duration**. Each medication becomes one line of the structured prescription, which the patient sees in their Consults tab.

### 1.12 Consultation notes, prescription and signed report

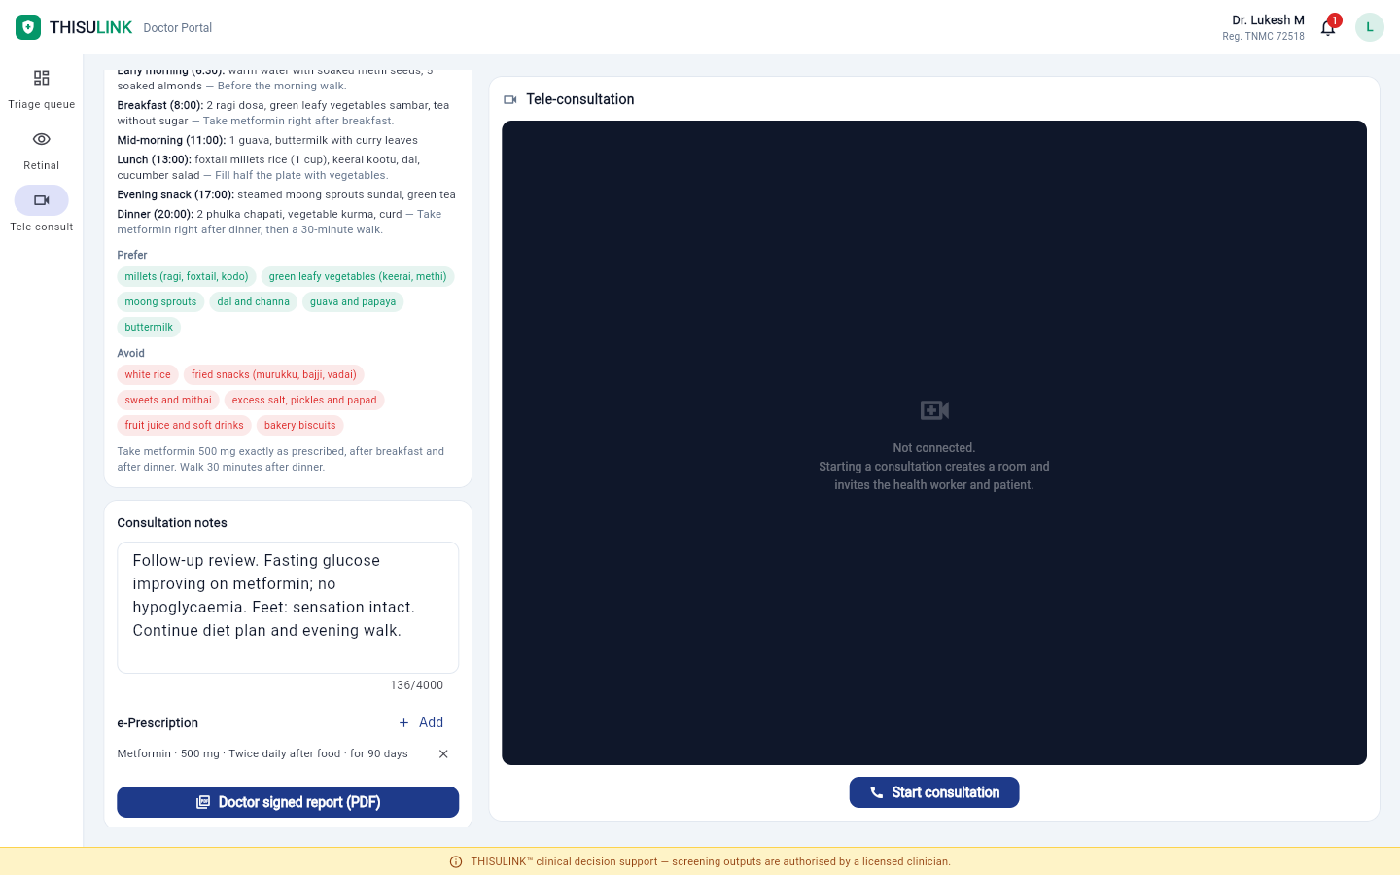
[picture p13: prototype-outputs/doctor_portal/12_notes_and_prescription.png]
Notes, prescription and report button


- **Consultation notes.** History, examination and advice (up to 4000 characters). The AI diet plan is generated from these notes.
- **e-Prescription list.** Each medication can be removed with the ×.
- **Doctor signed report (PDF).** Builds and downloads a report containing the patient header, retinal findings, recent vitals, notes, prescription and the current diet plan, electronically signed with the doctor's name and registration number.

### 1.13 Account menu

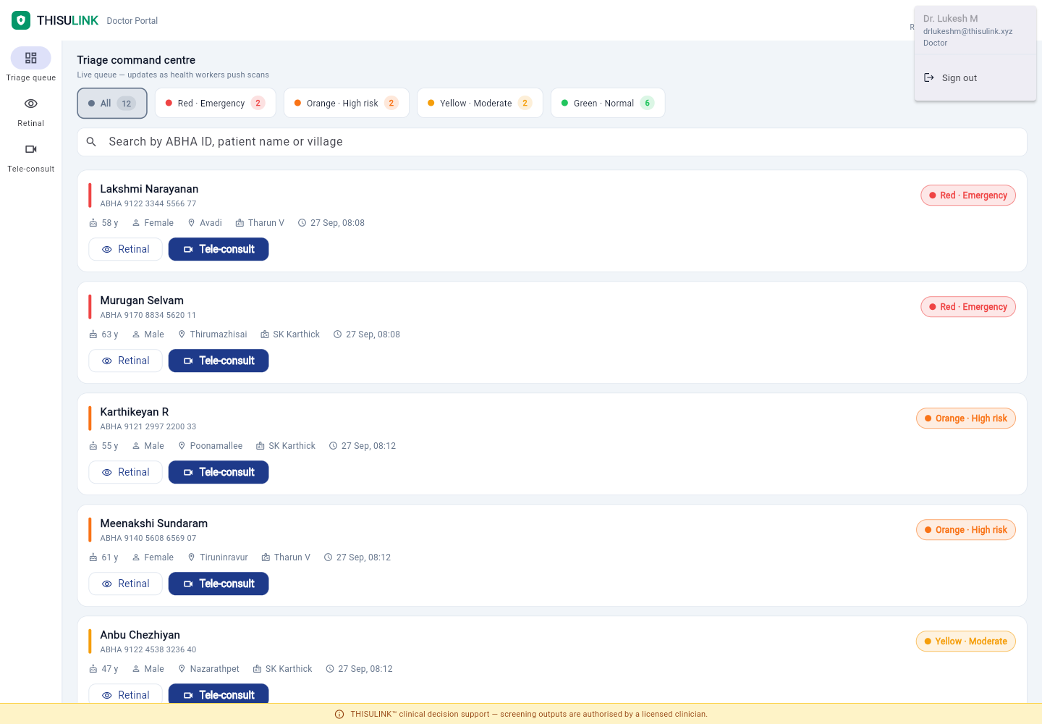
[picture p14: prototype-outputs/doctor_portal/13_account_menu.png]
Account menu


Opened from the avatar at the top right. It shows the signed-in doctor's name, email and role, and has **Sign out**.

### 1.14 Signed consultation report

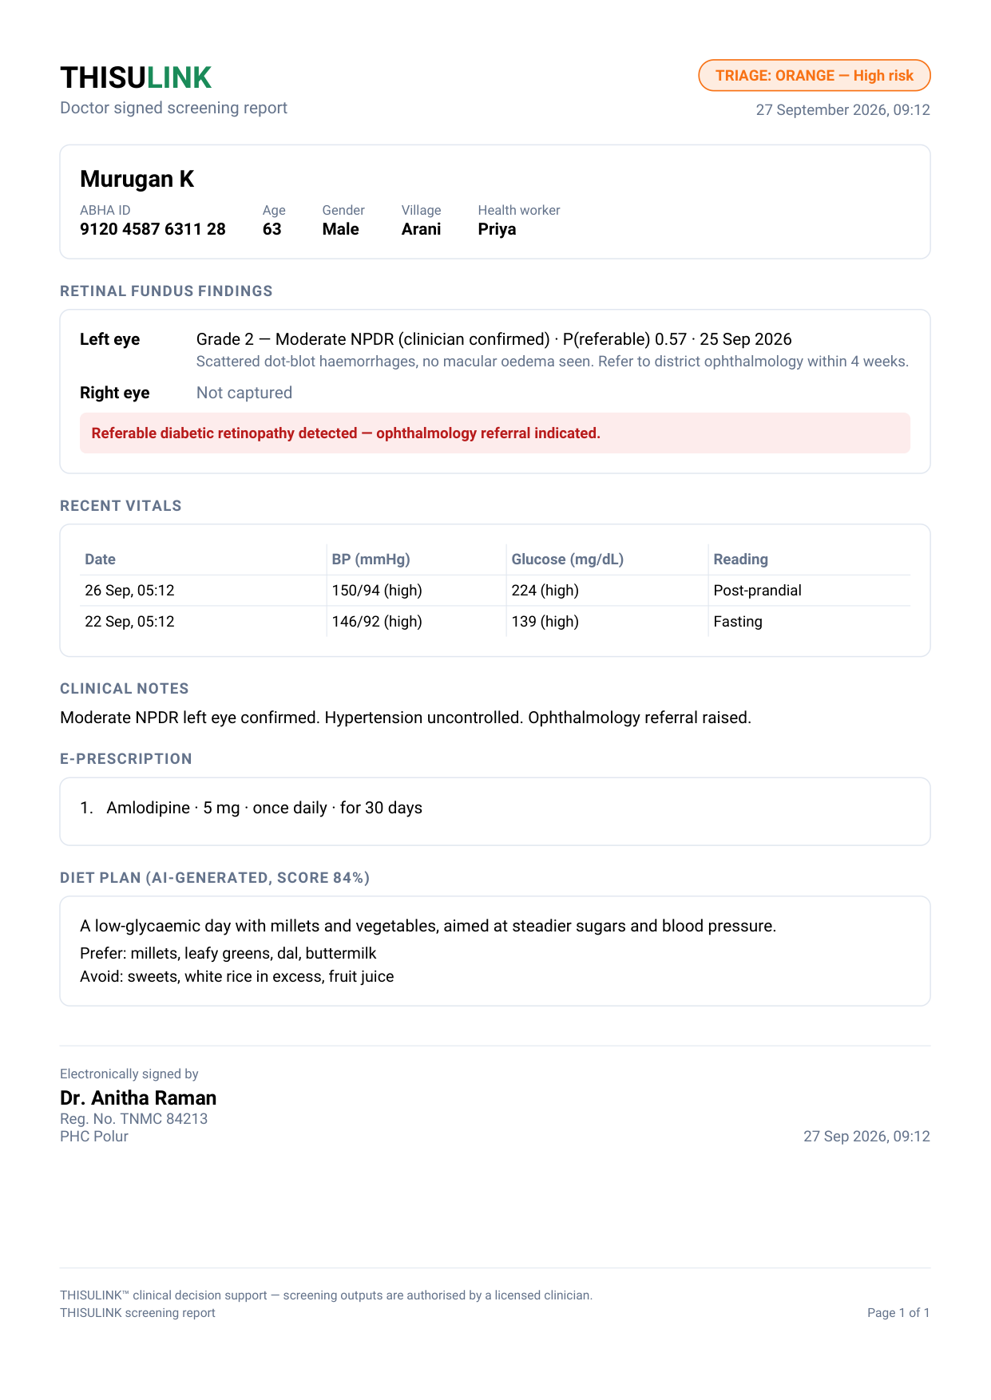
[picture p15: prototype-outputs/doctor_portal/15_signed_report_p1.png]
Signed consultation report, page 1


The PDF produced by **Doctor signed report (PDF)** (see 1.12), shown here for a demo patient with a referable retinal finding.

- **Header.** THISULINK wordmark, the patient's triage tier and urgency, and the date and time the report was generated.
- **Patient block.** Name, ABHA ID, age, gender, village and health worker.
- **Retinal fundus findings.** The latest capture of each eye: grade, whether it is AI-only or clinician confirmed, P(referable) and date, with the doctor's notes. A red banner appears when referable diabetic retinopathy is detected.
- **Recent vitals, clinical notes, e-Prescription and diet plan.** The last few readings, the consultation notes, each prescribed medication, and the summary and prefer/avoid lists of the current AI diet plan with its accuracy score.
- **Signature.** Electronically signed with the doctor's name, registration number and PHC. The intended-use disclaimer and page number are on every page.
- Text is set in Roboto, embedded in the PDF, so symbols such as the em dash (—) and ™ print correctly.

---

## 2. Health Worker app (Clinical Diagnostic Suite)

Used by: **frontline health workers**. Signed in here as *SK Karthick*. The screenshots are from the Windows desktop build. The Android build has the same screens.

### 2.1 Sign in

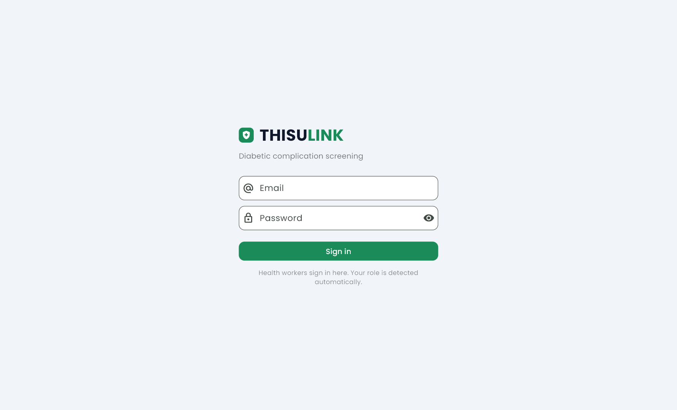
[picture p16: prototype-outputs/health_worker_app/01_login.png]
Health worker sign-in


Email and password sign-in. The role is detected automatically. The last signed-in health worker can also sign in offline, because a local credential is kept on the device.

### 2.2 Complete your account

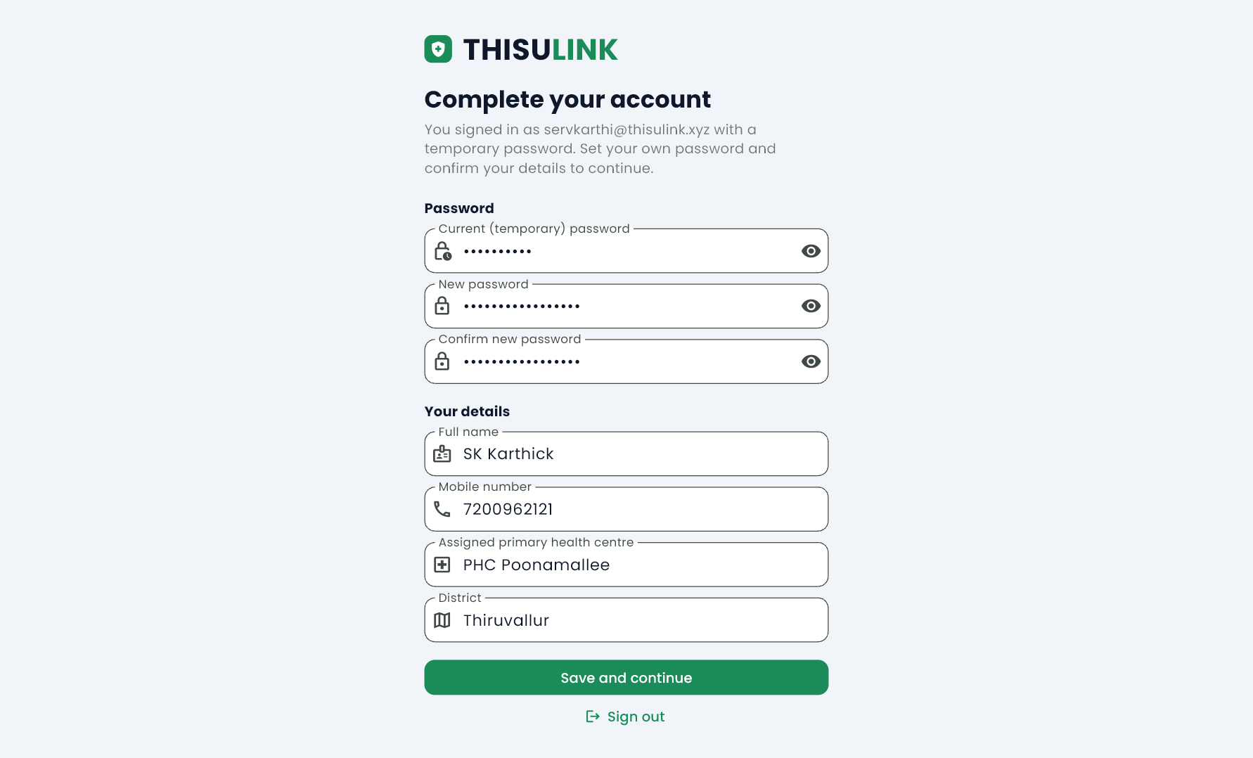
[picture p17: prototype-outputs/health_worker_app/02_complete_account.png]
Complete your account


Shown on first sign-in with a temporary password. Every other screen stays blocked until it is done.

- **Password.** Current (temporary) password, then the new password twice.
- **Your details.** Full name, mobile number, assigned primary health centre and district.
- **Save and continue** or **Sign out**.

### 2.3 Patient registry (today's caseload)

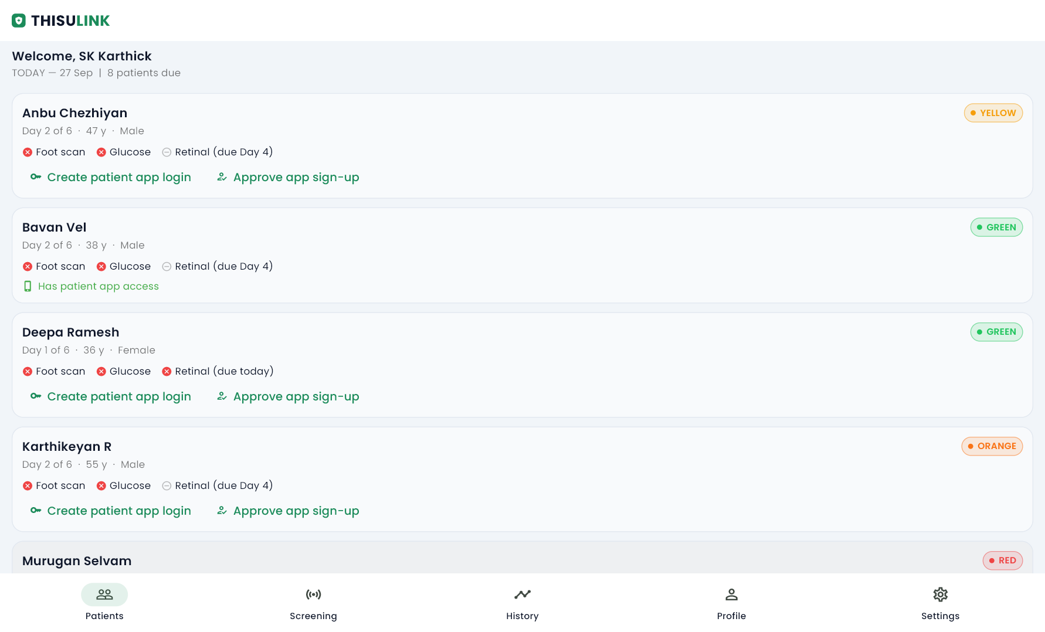
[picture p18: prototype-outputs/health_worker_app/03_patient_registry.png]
Patient registry

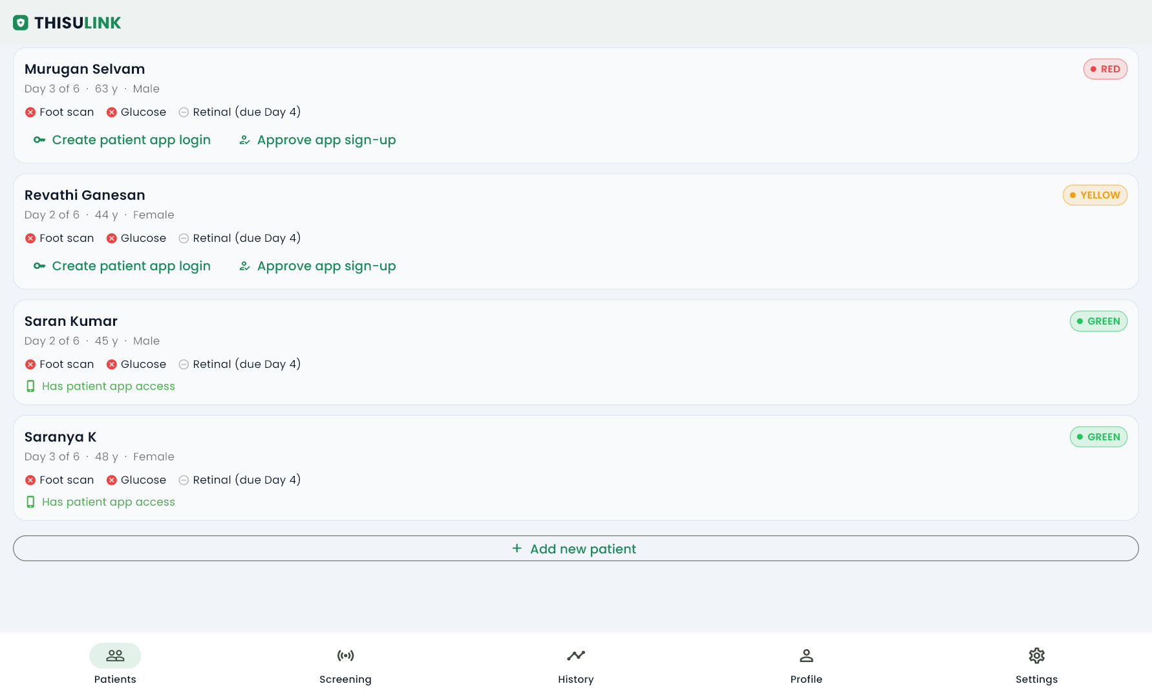
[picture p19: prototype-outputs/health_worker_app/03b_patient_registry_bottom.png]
Registry bottom with Add new patient


The health worker's home tab: every patient assigned to them.

- **Header.** A greeting, today's date and the number of patients due.
- **Patient card.** Name, day of the 6-day cycle, age, gender and triage tier. Ticks show what is still due today: **Foot scan**, **Glucose** and **Retinal**. Retinal is due on days 1 and 4.
- **Patient app access.** A card shows either *Has patient app access*, or two actions: **Create patient app login** (see 2.5) and **Approve app sign-up** (see 2.7).
- Clicking a card opens that patient's **Screening** session.
- **Add new patient** at the bottom of the list (see 2.4).
- **Bottom navigation.** Patients, Screening, History, Profile and Settings.

### 2.4 Add new patient

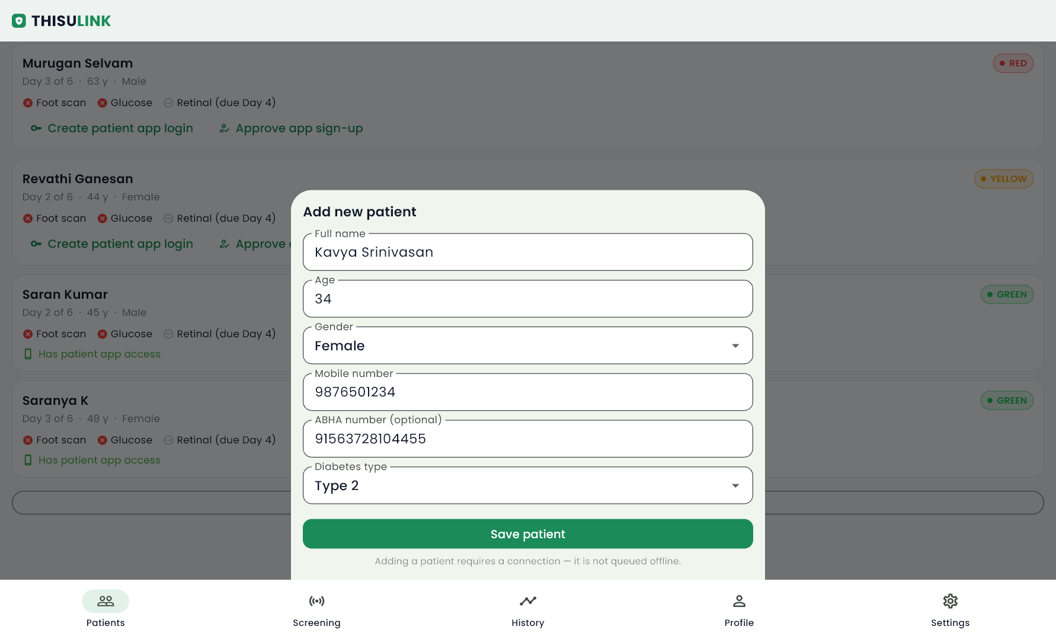
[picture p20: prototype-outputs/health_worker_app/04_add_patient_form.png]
Add new patient form


Enrols a patient into the health worker's caseload. Fields: **Full name**, **Age**, **Gender**, **Mobile number** (later used as the patient's app username), **ABHA number** (optional, 14 digits) and **Diabetes type**. Adding a patient needs a connection to the server and is not queued offline.

### 2.5 Create patient app login

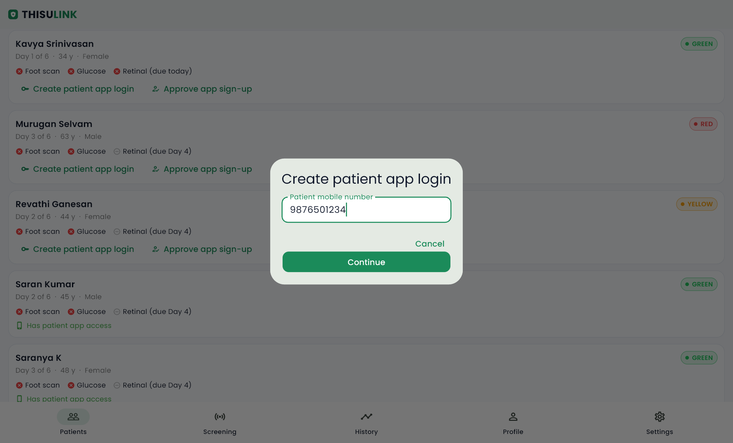
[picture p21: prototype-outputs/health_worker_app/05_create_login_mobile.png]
Create login — mobile number


Creates a Health Companion login for a patient who does not have one. The patient's mobile number is pre-filled and becomes their username.

### 2.6 One-time password

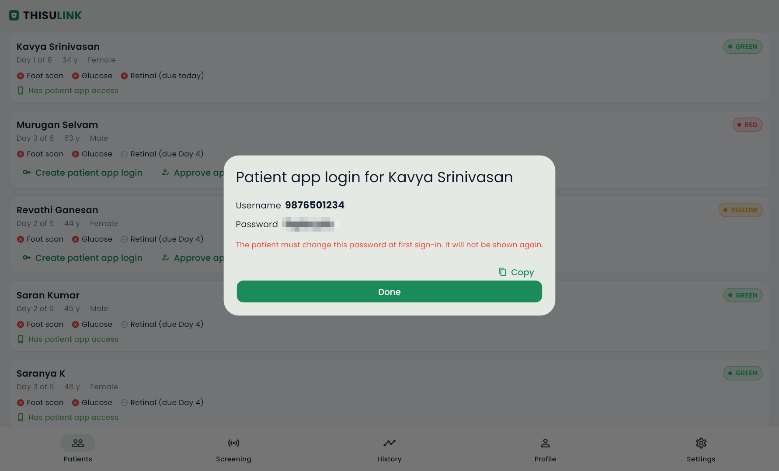
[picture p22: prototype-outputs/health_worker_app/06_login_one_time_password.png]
One-time password


The server generates a one-time password (blurred here) and shows it **only once**, with a **Copy** button. The health worker gives it to the patient, who must change it at first sign-in (see 3.4).

### 2.7 Approve an app sign-up

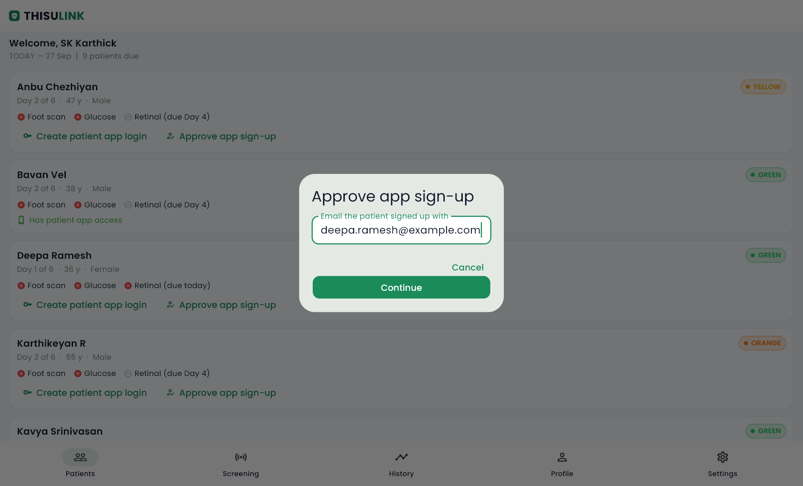
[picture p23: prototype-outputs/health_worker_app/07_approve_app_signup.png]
Approve app sign-up

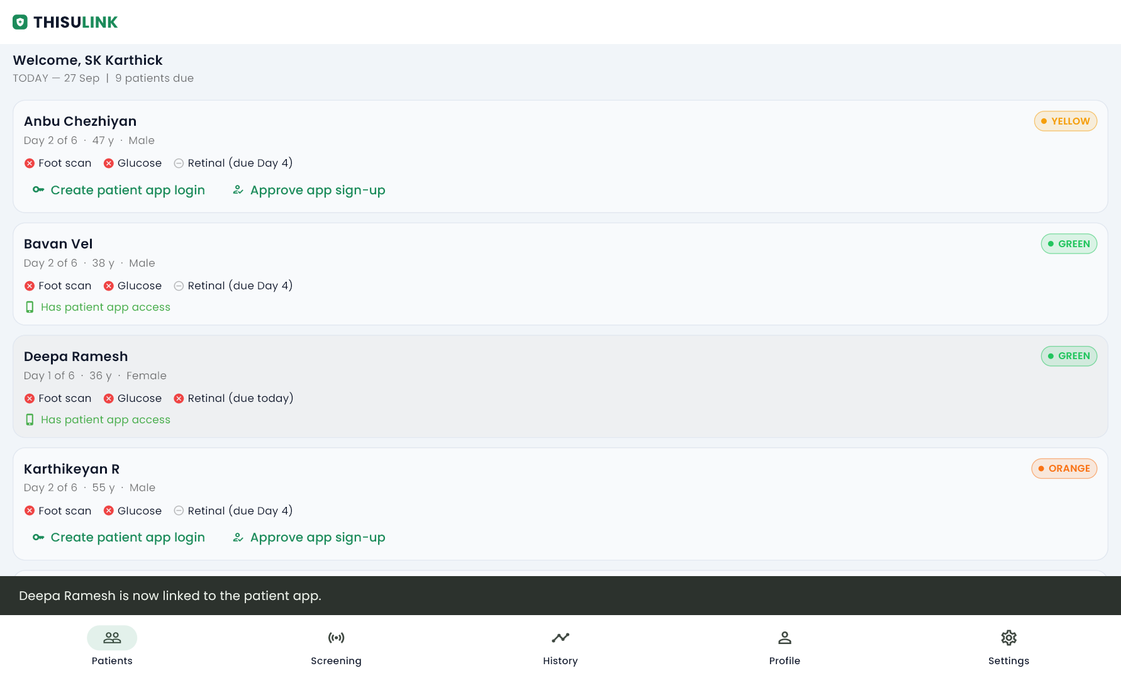
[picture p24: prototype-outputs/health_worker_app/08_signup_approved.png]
Sign-up approved


For patients who created their own account in the patient app (see 3.2 and 3.3). The health worker enters the email the patient signed up with. The server checks that the account is a patient account not linked to anyone else, then links it to this patient record. A confirmation appears and the card changes to *Has patient app access*.

### 2.8 Screening session

Screening session

The daily session for one patient. The drop-down at the top switches between patients and shows each one's cycle day and tier. There are four numbered steps:

1. **Connect probe.** Pair with the THISULINK foot probe over Bluetooth (WinRT on Windows).
2. **Foot scan (30 sec).** Available once the probe is connected.
3. **Blood glucose & BP.** Enter glucose manually or take the CGM value from the probe. BP is optional.
4. **Retinal photo (Day 1 & 4).** Import a fundus photo for the right or left eye.

**Submit session** saves everything locally first, then uploads it when there is a connection.

### 2.9 Foot scan with the probe

Foot scan running
Foot scan result

- **While scanning.** A live **contact force** reading with an OK check (the accepted window is 1.40–1.60 N), a progress bar with the count of valid samples, and running values for shear-wave speed (c_s) and Young's modulus (E).
- **Result.** Averaged c_s and E, the **tissue class** (A healthy, B early glycation, C diabetic neuropathy) with its tier colour, and the **thermal asymmetry dT** between the feet (2.2 °C is the escalation threshold). It also shows how many packets were used and how many were rejected. **Rescan** repeats the scan.
- The blue banner shows that the **simulated probe stream** is on. It exists for demos and training, and a session recorded with it cannot be submitted.

### 2.10 Glucose, blood pressure and fundus import

Vitals and fundus import

- **Glucose** in mg/dL. **Use CGM value** copies the value from the probe packet.
- **Systolic / Diastolic** in mmHg (shown here as 128 / 82). Optional, but if one is entered both are required.
- **Retinal photo.** Choose *Right eye* or *Left eye*, then **Import fundus image** (JPEG or PNG from the fundus camera or a USB drive). The image is previewed with **Retake** and **Use this**. The app then grades it with the on-device ONNX model, or with the server when the model is not available. If neither is available (as on the test server here), the image is kept **ungraded for doctor review**.
- **Submit session** stays disabled while the simulated probe is on.

### 2.11 Patient history

History charts
DR grade, triage timeline and sessions

Trends across the 6-day cycle for the selected patient:

- **Shear-wave elastography (E, kPa)**, with bands for A (50 or below), B (51–150) and C (above 150).
- **Thermometry (dT, °C)**, with a red line at the 2.2 °C threshold.
- **Blood glucose (mg/dL)**, with normal, watch and elevated bands.
- **DR grade**, drawn as a step across the retinal capture days.
- **Triage timeline** (one dot per session) and the **Sessions** list, with the day, tier, glucose and DR grade, including whether the grade was reviewed by a doctor.

Sessions pulled from the server get their tier from the same triage rules as a session recorded on the device, using the latest reading of each kind up to that day. Murugan Selvam, shown here, goes from YELLOW (glucose 288) to ORANGE (referable DR, glucose 312) to RED (doctor-confirmed grade 3), which matches his RED tier on the server. A session with nothing to triage on (blood pressure only, for example) is shown as a grey UNKNOWN, never as GREEN. A reading without a stored cycle day is placed on the day the server would give it: the count of distinct visit days (IST) so far, wrapping after day 6.

### 2.12 Profile

Profile

The signed-in health worker's name, email, phone, district, primary health centre and role, with **Sign out**. Signing out clears the stored token and any local drafts, including scans that have not uploaded yet.

### 2.13 Settings (probe, reminders, sync)

Settings

- **Probe.** Connection status and Connect, the device-name prefix, the accepted contact force, the Bluetooth stack, and the **Simulate probe stream** switch for demos.
- **Reminders.** Notification permission, and a **Vital check** that normally runs every 15 minutes in the background (on Android), with **Run now**.
- **Sync.** The backend address in use, the number of **queued sessions** waiting to upload, and **Sync now → Upload**.

---

## 3. Patient app (Health Companion)

Used by: **patients**. Signed in here as *Saranya K*. The screenshots use a phone-sized screen.

### 3.1 Sign in

Patient sign-in

- **Email or mobile number** and **Password**. A patient enrolled by a health worker signs in with their mobile number and the temporary password they were given.
- **Forgot password?**, **Create an account** (see 3.2) and **Server settings** (to point the app at a local-network server in a field camp).

### 3.2 Create your account

Register

Self sign-up with full name, email, an optional mobile number and a password (entered twice). After signing up, the patient visits their health worker once to be approved (see 2.7).

### 3.3 Waiting for approval

Pending approval

Shown after sign-up until a health worker links the account to a patient record. It shows the email the health worker must enter. **Check again** re-checks the link and **Sign out** leaves.

### 3.4 First sign-in: details and new password

Welcome — details
Welcome — password

Shown the first time a patient signs in with a temporary password from their health worker.

- **Your details.** Full name, age, gender, village or town, diabetes type and mobile number, pre-filled from the patient record so the patient can correct them.
- **Your password.** The temporary password, then a new password entered twice.
- **Save and continue** opens the app.

### 3.5 Home

Home
Home scrolled

- **Monitoring cycle.** A ring showing the day of the 6-day cycle, a reminder to log glucose today, and **Record a reading**.
- **Next consultation.** The upcoming consultation: the doctor's name and specialisation (e.g. *Dr. Lukesh M, Diabetology*), when it was booked, and its status (*Scheduled*, or *Doctor is ready* with a **Join** button once the doctor starts the call). **All** opens the Consults tab.
- **Latest readings.** The latest glucose and BP. **History** opens the Readings tab.
- **Your diet plan.** A preview of the current AI diet plan. Tapping it opens the Diet tab.
- **Bottom navigation.** Home, Readings, Consults, Diet and Profile.

### 3.6 Readings and trends

Readings summary and chart
Readings — time in range and averages
Readings — blood pressure and history

- **Average, lowest and highest** glucose.
- **Glucose chart** with the 70–180 mg/dL target band. Points above the target are orange. The y-axis is labelled in even steps, and the time axis shows the first and last reading dates.
- **Time in range.** The percentage of readings below, within and above range, described in plain words.
- **Average by when you tested.** Fasting and after-meal readings are averaged separately.
- **Blood pressure.** The latest reading and the average of the last 7.
- **All readings.** A list of every entry. An entry recorded offline shows as *Waiting to upload* until it syncs.
- **Record reading** (floating button).

### 3.7 Record a reading

Record a reading

- **Blood glucose** in mg/dL.
- **When was it taken?** *Fasting*, *After a meal* or *Any time*.
- **Blood pressure (optional).** Top (systolic) and bottom (diastolic).
- **Save reading.** Saved with the current time. The app does not interpret the reading; the care team reviews it at the consultation.

### 3.8 Consultations

Consultations

Each card shows the doctor's name and specialisation, and a date that says which date it is: *Booked* (when the consultation was booked; there is no appointment time), *Started* (a call in progress), or *Held* (when a completed call took place).

- **Upcoming.** Scheduled consultations. A **Join** button appears when the doctor starts the video call.
- **Past.** Completed consultations, with the date held and the doctor's **prescription** (drug, dose, frequency, duration and notes).

### 3.9 Diet plan

Diet plan summary
Diet plan meals
Diet plan prefer/avoid

The AI plan generated from the doctor's consultation remarks, with the date it was made.

- **Summary** and **Daily targets** (calories, carbohydrate, protein, fat, water).
- **Meals.** Each meal with its time, items and a short note, such as when to take a medicine.
- **Choose more often** and **Avoid or limit** food chips, then **Notes**.
- A footer reminds the patient that the plan supports, and does not replace, the doctor's advice.

### 3.10 Profile

Profile

- **Patient record.** ABHA ID, age, gender, village, diabetes type and cycle day. It is read-only and kept up to date by the health worker.
- **Account.** The email or mobile number the patient signed in with.
- **Appearance.** Match my phone, Light or Dark.
- **Server.** The server address, which can be changed for a local-network server.
- **Sign out.**

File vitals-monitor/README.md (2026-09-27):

# THISULINK™ Vitals Integration — COTS BLE Architecture

| | |
|---|---|
| **Document** | VIT-SPEC-001 |
| **Subsystem** | Routine vitals capture (blood pressure, blood glucose) |
| **Integration model** | Commercial off-the-shelf devices, Bluetooth SIG standard profiles |
| **Status** | Architecture specified — see §7 |

---

## 1. Design position

THISULINK does **not** manufacture a blood pressure monitor or a glucometer. It
integrates with certified commercial devices over the standard Bluetooth SIG
profiles they already implement.

### Why COTS, and why the cuffless optical model was removed

An earlier design explored cuffless optical (PPG-based) blood pressure
estimation. **That approach is removed from the platform.**

| | Cuffless optical BP | COTS oscillometric cuff |
|---|---|---|
| Regulatory status | No accepted validation standard | ISO 81060-2 validated |
| Calibration | Per-patient, drifts within days | Factory, stable |
| Failure mode | Plausible wrong number | Error code or no reading |
| Clinical acceptance | Not accepted for diagnosis | Standard of care |

The deciding factor is the failure mode. A cuff that fails tells the patient it
failed. A cuffless estimator that drifts returns a number that looks exactly
like a good number — and in a platform whose entire purpose is to escalate
patients on threshold crossings, a silently biased input corrupts triage
without ever appearing broken.

Building an unvalidated measurement device is also the slowest possible route
to market: it converts a software product into a regulated hardware product.
Integrating certified devices inherits their validation.

---

## 2. Supported profiles

### 2.1 Blood Pressure

| Attribute | UUID | Operation |
|---|---|---|
| Blood Pressure Service | `0x1810` | — |
| Blood Pressure Measurement | `0x2A35` | **Indication** |
| Intermediate Cuff Pressure | `0x2A36` | Notify (optional, live display) |
| Blood Pressure Feature | `0x2A49` | Read |

**Conformance target:** ISO 81060-2 validated devices.

`0x2A35` uses **indication**, not notification — it is acknowledged at the ATT
layer. A blood pressure reading is a clinical record; the protocol guarantees
delivery rather than assuming it.

#### Measurement structure

| Field | Presence | Notes |
|---|---|---|
| Flags | Mandatory | Unit selection, optional field presence |
| Systolic / Diastolic / MAP | Mandatory | IEEE-11073 16-bit SFLOAT |
| Timestamp | Optional | Device clock — see §4.2 |
| Pulse rate | Optional | SFLOAT |
| Measurement status | Optional | Body-movement, cuff-fit, irregular-pulse flags |

Values are **SFLOAT**, not integers. The special value `NaN` is a valid
transmission indicating the device could not obtain a reading — it must be
surfaced as a failed measurement, never coerced to zero.

The measurement status bits are retained, not discarded. A reading flagged for
body movement or improper cuff fit is stored with that flag, so a clinician
reviewing an outlier can see the device's own assessment of it.

### 2.2 Glucose

| Attribute | UUID | Operation |
|---|---|---|
| Glucose Service | `0x1808` | — |
| Glucose Measurement | `0x2A18` | **Notify** |
| Glucose Measurement Context | `0x2A34` | Notify (optional) |
| Record Access Control Point | `0x2A52` | Write / Indicate |

**Conformance target:** ISO 15197 validated devices.

#### Record Access Control Point

Glucometers store readings taken while unpaired. The RACP is how the backlog is
retrieved:

```
   Client                                    Glucometer
     │                                            │
     ├── write RACP: "report records > seq N" ───►│
     │                                            │
     │◄── notify 0x2A18: record N+1 ──────────────┤
     │◄── notify 0x2A18: record N+2 ──────────────┤
     │◄── notify 0x2A18: record N+3 ──────────────┤
     │                                            │
     │◄── indicate RACP: "N records reported" ────┤
     │                                            │
```

The sequence number of the last ingested record is persisted per device. A
patient who tests for a week without their phone nearby syncs the full week on
next connection, in order, with no duplicates and no gaps.

### 2.3 Transparent UART bridge — legacy clinic meters

Clinic meters predating BLE GATT profiles expose a serial interface. A
transparent UART BLE bridge module carries that stream.

| Aspect | Handling |
|---|---|
| Transport | Vendor-specific transparent UART service |
| Framing | Per meter model — no standard exists |
| Parser | Per-model adapter behind a common interface |
| Provenance | Record tagged `bridge:<model>` |

Bridged readings carry a provenance marker distinguishing them from readings
obtained over a standard profile. The transport is not certified and the
parsing is model-specific; a clinician reviewing the record is entitled to know
which path a number arrived by.

---

## 3. Acquisition flow

```
  [ COTS device ]
        │ BLE GATT — 0x1810 indication / 0x1808 notification
        ▼
  ┌─────────────────────────────────────────────┐
  │  Companion client — background BLE listener │
  │  • profile decode (SFLOAT, flags, status)   │
  │  • unit normalisation                       │
  │  • plausibility gate                        │
  └─────────────────────────────────────────────┘
        │
        ▼
  ┌─────────────────────────────────────────────┐
  │  Local encrypted SQLite — written FIRST     │
  │  status = PENDING                           │
  └─────────────────────────────────────────────┘
        │
        ├── offline ──► remains queued, patient sees the reading
        │
        └── online ───► PUSH to vitals_records
                             │
                        ┌────┴────┐
                     success    failure
                        │           │
                  status=SYNCED   exponential backoff
                  server id        2, 4, 8 … 60 min
                  recorded
```

The device is the source of truth for the measurement; the local database is
the source of truth for whether it has been delivered. A reading is durable the
instant it is decoded, before any network operation is attempted.

---

## 4. Data handling

### 4.1 Normalisation

| Quantity | Stored as | Wire source |
|---|---|---|
| Systolic / diastolic | Integer mmHg | SFLOAT, kPa converted where flagged |
| Blood glucose | Integer mg/dL | SFLOAT, mmol/L converted where flagged |
| Reading context | `fasting` / `post_prandial` / `random` | Measurement Context, else patient-declared |

Unit flags are honoured per reading, never assumed per device. A device may be
reconfigured between readings, and a kPa value stored as mmHg is a fourfold
error in a field that drives escalation.

### 4.2 Timestamp authority

Device clocks drift and are frequently unset after a battery change. Every
record therefore carries:

| Field | Source | Purpose |
|---|---|---|
| `measured_at` | Device timestamp when present, else ingestion time | Clinical ordering |
| `created` | Server, at insert | Immutable audit ordering |

Where a device timestamp is implausible — future-dated, or preceding the
device's own last sync — ingestion time is used and the record is flagged. A
misordered glucose series changes which readings are read as fasting.

### 4.3 Plausibility gate

Readings outside physiological bounds are stored and flagged, never silently
dropped:

| Quantity | Accepted range |
|---|---|
| Systolic | 40 – 300 mmHg |
| Diastolic | 20 – 200 mmHg |
| Blood glucose | 0 – 1000 mg/dL |

A rejected-looking value may be a device fault or a genuine emergency. The
platform is not entitled to decide which by discarding it.

---

## 5. Backend contract

Readings land in `vitals_records`:

| Field | Type | Notes |
|---|---|---|
| `patient_id` | relation → `patients` | Required |
| `operator_id` | relation → `users` | Self for home readings |
| `systolic_bp` | number | mmHg |
| `diastolic_bp` | number | mmHg |
| `blood_glucose` | number | mg/dL |
| `reading_type` | select | `fasting` \| `post_prandial` \| `random` |
| `measured_at` | date | Clinical time |
| `cycle_day` | number | 1–6 screening cycle position |

Insertion triggers server-side triage recomputation. Glucose thresholds
(>180 / >300 / >400 mg/dL) participate directly in tier assignment — see
[backend/README.md](../backend/README.md).

---

## 6. Pairing and security

| Requirement | Specification |
|---|---|
| Pairing | LE Secure Connections where the device supports it |
| Bonding | Persisted per patient device |
| Multi-user | Bonds scoped to the authenticated account |
| Shared devices | Reading attributed to the signed-in patient at ingestion |

A shared household or clinic device is a real deployment case. Attribution is
resolved at ingestion against the authenticated session — never inferred from
which device transmitted.

---

## 7. Implementation status

| Component | Status |
|---|---|
| Profile specification and record contract | Specified |
| `vitals_records` collection | **Live in production** |
| Triage integration on glucose thresholds | **Live and verified** |
| Manual vitals entry (Clinical Diagnostic Suite) | Implemented |
| Offline queue, backoff, two-way sync engine | Implemented and unit-tested |
| **COTS BLE auto-capture (`0x1810` / `0x1808`)** | **Not implemented** |
| **RACP backlog retrieval** | **Not implemented** |
| **Transparent UART bridge adapters** | **Not implemented** |

The backend, storage, sync and triage paths for vitals are live today, carrying
seeded clinical data. The automatic BLE capture path described in §2 is
specified but not yet built; vitals currently reach the platform through manual
entry in the Clinical Diagnostic Suite.

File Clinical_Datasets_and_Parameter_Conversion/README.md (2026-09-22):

# Clinical Data Sources, Biomechanical Theory & Parameter Conversion Architecture





This document provides the exhaustive scientific, clinical, mathematical, and data-sourcing reference explaining:
1. **Where all baseline clinical datasets and numerical parameters originate.**
2. **The exact 5-step mathematical physics pipeline converting raw platform sensor readings (volts, counts, time delay) into quantitative diabetic tissue health indices.**

---

## 1. Clinical Data Sourcing & Reference Literature

THISULINK's biomechanical thresholds, tissue density constants, and thermal criteria are directly grounded in peer-reviewed clinical research and open clinical databases:
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

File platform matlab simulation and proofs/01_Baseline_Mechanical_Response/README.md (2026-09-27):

# Experiment 01: Baseline Mechanical Response Under Calibrated Preload

## 1. Executive Summary & Clinical Context
The **THISULINK** plantar biomechanical platform launches transient low-frequency shear waves into the plantar heel pad / 1st metatarsal head to evaluate tissue stiffness changes indicative of diabetic neuropathy.
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

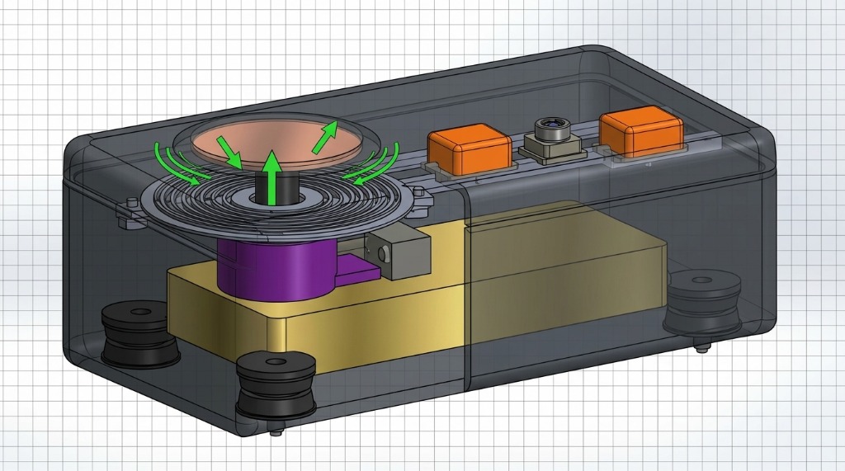
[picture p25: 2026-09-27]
hardware/cad/plantar_platform_isometric_cad.jpg

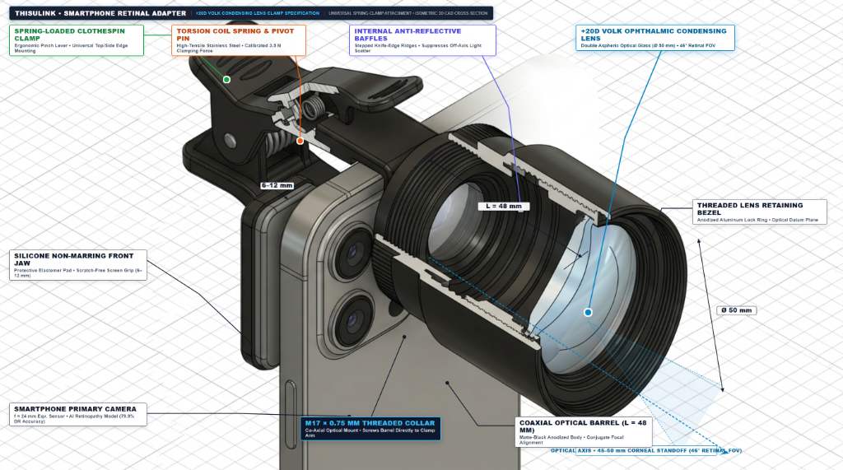
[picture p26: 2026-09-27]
hardware/cad/retinal_adapter_cross_section_cad.png

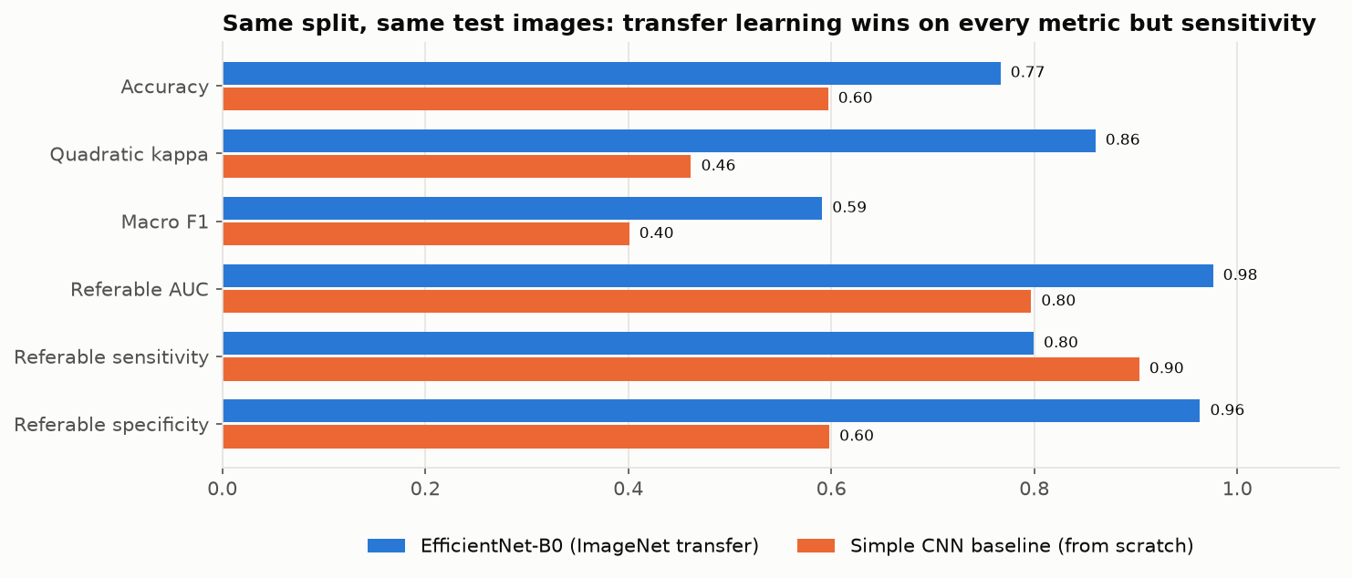
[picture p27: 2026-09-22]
retinal-screening/docs/images/model_comparison.png

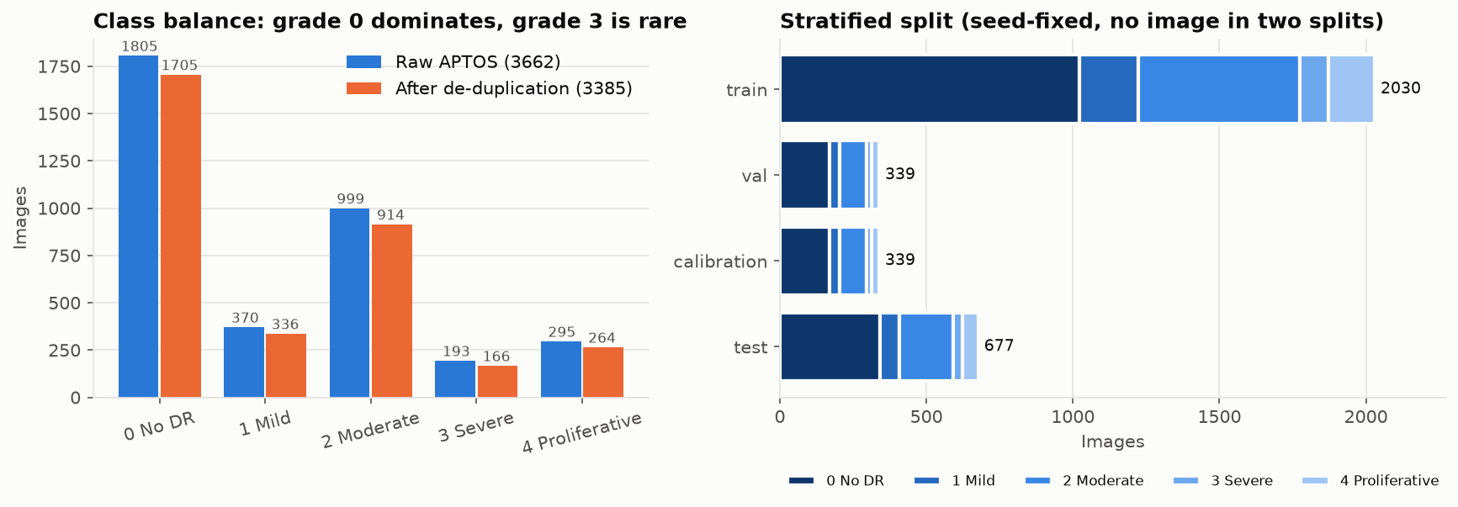
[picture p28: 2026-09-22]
retinal-screening/docs/images/dataset_distribution.png

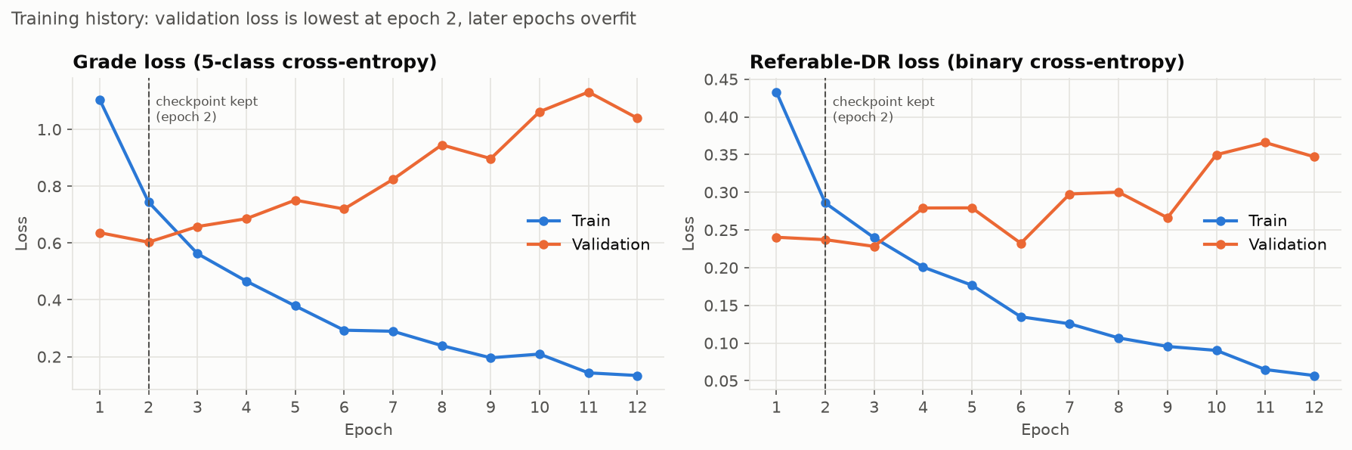
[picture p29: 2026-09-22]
retinal-screening/docs/images/learning_curves.png

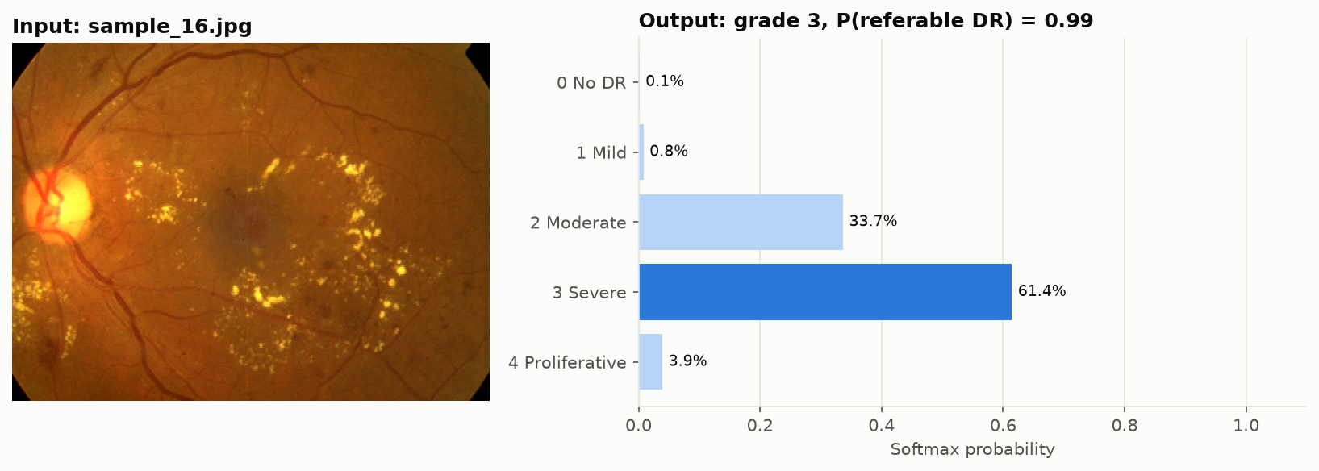
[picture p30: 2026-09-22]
retinal-screening/docs/images/single_prediction.png

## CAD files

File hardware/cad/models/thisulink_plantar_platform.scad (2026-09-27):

// ============================================================
//  THISULINK™ — Plantar Shear-Wave Elastography Platform
//  OpenSCAD Parametric Model — HW-SPEC-001 compliant
//  All component dimensions from manufacturer datasheets
//  Units: mm
// ============================================================
//
//  REFERENCE IMAGE LAYOUT:
//  ┌──────────────────────────────────────────────────────┐
//  │  LEFT BAY (~60%)          │  RIGHT BAY (~40%)        │
//  │                           │                          │
//  │   [copper contact plate]  │  [ESP32] [MLX] [ESP32]   │
//  │   [spiral spring disc]    │                          │
//  │   [VCA purple cylinder]   │                          │
//  │   [plunger + guide]       │                          │
//  │   ====== brass base ==============================   │
//  │ [foot]              [foot]│              [foot][foot] │
//  └──────────────────────────────────────────────────────┘
//
//  Sensor positions (§5 of hardware/README.md):
//    VCA actuator axis  :  x_act (variable, ~50 mm)
//    ADXL355 pickup 1   :  x₁ = 105 mm from actuator
//    ADXL355 pickup 2   :  x₂ = 145 mm from actuator
//    Baseline Δx        :  40 mm (FIXED — 1 mm error = 2.5%)
//
// ============================================================

$fn = 96;   // smooth curves for final render

// ============================================================
// §A — ENCLOSURE (PETG 3D-printed shell)
// ============================================================
enc_length = 200;    // X — long axis
enc_width  = 110;    // Y — depth
enc_height = 68;     // Z — total outer height
enc_wall   = 3.0;    // shell thickness
enc_floor  = 4.0;    // floor plate
enc_lid    = 3.0;    // lid plate
enc_fillet = 8;      // corner radius

// ============================================================
// §B — RUBBER VIBRATION-ISOLATION FEET (4×)
//       (§7: "without isolation, VCA excitation couples
//        into examination surface")
// ============================================================
foot_r       = 10;     // mushroom cap radius
foot_h_cap   = 5;      // cap height
foot_h_neck  = 4;      // tapered neck
foot_h_base  = 6;      // threaded insert portion
foot_r_neck  = 4;      // neck radius (M4 thread)
foot_inset_x = 16;     // from enclosure corner X
foot_inset_y = 16;     // from enclosure corner Y

// ============================================================
// §C — BRASS STRUCTURAL BASE BLOCK
//       (machined C360 brass, mounting platform)
// ============================================================
brass_w = enc_length - 2*enc_wall - 4;   // fits inside shell
brass_d = enc_width  - 2*enc_wall - 4;
brass_h = 16;                             // block height
brass_z = enc_floor;

// ============================================================
// §D — VOICE COIL ACTUATOR (VCA) — Direct-Drive
//       (§3: 10–300 Hz, 0.100 N dynamic force)
//       Miniature housed VCA: ⌀20 mm OD, 25 mm height
// ============================================================
vca_x       = 55;           // X centre inside enclosure
vca_y       = enc_width/2;  // centred on Y
vca_z       = brass_z + brass_h;
vca_od      = 20;           // outer diameter (housing)
vca_h       = 25;           // housing height
vca_coil_od = 14;           // coil bobbin OD
vca_coil_id = 8;            // coil bobbin ID
vca_coil_h  = 16;           // coil winding height
vca_mag_h   = 3;            // top magnet plate

// ============================================================
// §E — PLUNGER & LINEAR GUIDE
//       Brass plunger with PTFE bushing, spring-loaded
//       Transmits VCA force to silicone pad
// ============================================================
plunger_r     = 5;     // plunger shaft radius
plunger_h     = 18;    // total shaft length
plunger_guide_w = 14;  // guide block width
plunger_guide_d = 14;  // guide block depth
plunger_guide_h = 12;  // guide block height

// ============================================================
// §F — SPIRAL SPRING / FLEXURE DISC
//       Allows axial motion, constrains lateral
//       Concentric ring pattern (visible in ref image)
// ============================================================
spring_disc_r   = 32;   // outer radius of flexure
spring_disc_h   = 4;    // disc thickness
spring_disc_z   = vca_z + vca_h + 2;
spring_n_rings  = 8;    // number of concentric grooves
spring_ring_w   = 1.5;  // groove width

// ============================================================
// §G — COPPER CONTACT PLATE (plantar coupling surface)
//       (§3: "Medical-grade silicone interface pad")
//       Copper disc on top of spring disc
// ============================================================
contact_r     = 28;    // contact plate radius
contact_h     = 5;     // plate thickness
contact_rim_h = 2;     // raised rim around edge
contact_z     = spring_disc_z + spring_disc_h;

// ============================================================
// §H — ADXL355 MEMS ACCELEROMETERS (2×)
//       Analog Devices, 6.0 × 6.0 × 2.1 mm, LCC-14
//       (§5: pickup 1 at x₁=105 mm, pickup 2 at x₂=145 mm)
//       Mounted on the spring disc surface
// ============================================================
adxl_w  = 6.0;    // datasheet: 6.00 mm
adxl_d  = 6.0;    // datasheet: 6.00 mm
adxl_h  = 2.1;    // datasheet: 2.1 mm
// Positions are relative to VCA axis, but for the platform
// model we place them on small PCB carrier boards
adxl_pcb_w = 12;   // carrier PCB
adxl_pcb_d = 12;
adxl_pcb_h = 1.6;  // FR-4 thickness
// Positions on the spring disc (relative to disc centre)
adxl1_offset_x = -8;   // pickup 1 (closer to VCA)
adxl2_offset_x = 8;    // pickup 2 (40 mm baseline away)

// ============================================================
// §I — TAL221 LOAD CELL
//       (§4: cantilever, 5 kg capacity)
//       47 × 12 × 6 mm, aluminium alloy, M3 holes
// ============================================================
lc_w = 47;    // datasheet: 47 mm
lc_d = 12;    // datasheet: 12 mm
lc_h = 6;     // datasheet: 6 mm
lc_x = vca_x + vca_od/2 + 8;     // next to VCA
lc_y = vca_y - lc_d/2;
lc_z = brass_z + brass_h + 1;
// M3 mounting holes at corners
lc_hole_r   = 1.6;    // M3 clearance
lc_hole_dx  = 38;     // hole spacing X
lc_hole_dy  = 0;      // single-row

// ============================================================
// §J — HX711 24-BIT ADC BREAKOUT
//       (§4: 24-bit, 80 SPS)
//       22 × 22 mm PCB
// ============================================================
hx_w = 22;    // datasheet: 22 mm
hx_d = 22;    // datasheet: 22 mm
hx_h = 4;     // board + components height
hx_x = lc_x + lc_w + 4;
hx_y = vca_y - hx_d/2;
hx_z = brass_z + brass_h + 1;

// ============================================================
// §K — MLX90621 16×4 FIR THERMAL ARRAY
//       (§6: Melexis, TO-39 package)
//       ⌀9.2 mm × 7 mm height, 4 leads
// ============================================================
mlx_r    = 4.6;    // TO-39: 9.2 mm diameter
mlx_h    = 7.0;    // can height
mlx_lens = 3.5;    // silicon lens window radius
mlx_lens_h = 1.5;  // lens protrusion
// Position: between the two ESP32 modules in right bay
mlx_x    = 150;
mlx_y    = enc_width/2;
mlx_z    = brass_z + brass_h + 1;

// ============================================================
// §L — ESP32-S3 DevKitC MODULES (MCU + BLE 5.0) (2×)
//       (§8: BLE 5.0, GATT 0xFFE0)
//       62.74 × 25.40 mm
// ============================================================
esp_w = 62.74;    // datasheet
esp_d = 25.40;    // datasheet
esp_h = 8;        // board + components
// Two modules side by side with MLX between them
esp1_x = mlx_x - mlx_r - 4 - esp_d;   // rotated 90° to fit
esp1_y = enc_width/2 - esp_w/2;
esp2_x = mlx_x + mlx_r + 4;
esp2_y = esp1_y;
esp_z  = brass_z + brass_h + 1;
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

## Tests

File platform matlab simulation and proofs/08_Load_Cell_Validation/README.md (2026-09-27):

# Experiment 08: Micro Load-Cell Contact Validation & Safety Interlock Logic

## 1. Safety Architecture: Automated Preload Gate
To prevent operator dependency and tissue pre-stress measurement distortion, the THISULINK platform integrates a precision miniature cantilever beam load cell monitored by an HX711 24-bit $\Sigma\Delta$ ADC. 

The firmware implements a strict contact validation state machine:
- **Target Preload**: $1.50\text{ N}$
- **Allowable Tolerance**: $\pm 0.10\text{ N}$ ($1.40\text{ N} - 1.60\text{ N}$)
- **Preload Noise Floor**: $\sigma_F = 0.015\text{ N}$ (HX711 24-bit filtered)

---

## 2. Firmware Interlock State Machine
$$\text{Status} = \begin{cases}
\text{LOCKOUT: INSUFFICIENT PRELOAD}, & F_{\text{meas}} < 1.40\text{ N} \\
\text{INTERLOCK CLEARED: WAVE LAUNCH AUTHORIZED}, & 1.40\text{ N} \le F_{\text{meas}} \le 1.60\text{ N} \\
\text{LOCKOUT: EXCESSIVE TISSUE PRE-COMPRESSION}, & F_{\text{meas}} > 1.60\text{ N}
\end{cases}$$

The Voice Coil Actuator (VCA) cannot physically trigger unless the HX711 registers a steady 300 ms baseline within the green window.

---

## 3. Results (simulation)
Numbers below are the console output of the script (GNU Octave 11.3 run of `master_run_all`). Synthetic noise comes from `common/det_randn.m`, so MATLAB prints the same values; ODE-based values can differ in the last digit between MATLAB and Octave.

| Trial | True preload | Mean measured (100 samples) | Decision |
|---|---|---|---|
| 1 | 0.85 N | 0.850 N | lockout (insufficient) |
| 2 | 1.32 N | 1.321 N | lockout (insufficient) |
| 3 | 1.51 N | 1.511 N | cleared |
| 4 | 1.58 N | 1.581 N | cleared |
| 5 | 1.85 N | 1.851 N | lockout (excessive) |
| 6 | 3.20 N | 3.201 N | lockout (excessive) |

All six decisions are correct. With σ = 0.015 N and 100-sample averaging (σ_mean ≈ 0.0015 N) misclassification is only possible within a few mN of the 1.40 / 1.60 N limits; this edge case is not tested here.

## 4. Limitations
- Gaussian noise on a constant force; no drift, creep, temperature effects, or foot movement during the 300 ms settle window. Described firmware behaviour is a specification, not tested firmware.

## 5. Generated Figures
- `load_cell_true_vs_measured.png`, `load_cell_validation_limits.png`

---

## How to Run
```matlab
cd('08_Load_Cell_Validation')
experiment_load_cell            % or run master_run_all from the suite root
```
Figures are written to `outputs/08_Load_Cell_Validation/` (git-ignored).

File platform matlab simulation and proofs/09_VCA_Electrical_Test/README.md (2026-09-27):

# Experiment 09: Voice Coil Actuator (VCA) Electromechanical Characterization

## 1. Electromechanical Architecture
The **THISULINK** platform utilizes a miniature linear Voice Coil Actuator (VCA) driven by a dual-H-bridge PWM driver (Texas Instruments DRV8833 / MAX22200). Unlike rotary eccentric mass (ERM) motors that suffer from frequency-amplitude coupling, a VCA provides independent control of frequency ($10 - 300\text{ Hz}$) and dynamic force amplitude ($100\text{ mN}$).

---

## 2. Governing Equations
The electrical impedance of the voice coil is:
$$Z(\omega) = R + j\omega L \implies |Z(\omega)| = \sqrt{R^2 + (\omega L)^2}$$

The current drawn under peak drive voltage $V_0 = 1.20\text{ V}$ is:
$$I_{\text{peak}}(\omega) = \frac{V_0}{|Z(\omega)|}, \quad I_{\text{rms}}(\omega) = \frac{I_{\text{peak}}}{\sqrt{2}}$$

The dynamic Lorentz force generated by the coil is:
$$F_{\text{peak}}(\omega) = K_f \cdot I_{\text{peak}}(\omega)$$

The average electrical power dissipation is:
$$P_{\text{elec}} = I_{\text{rms}}^2 \cdot R$$

---

## 3. Results (simulation, 50 Hz, $V_0$ = 1.20 V peak)
Numbers below are the console output of the script (GNU Octave 11.3 run of `master_run_all`). Synthetic noise comes from `common/det_randn.m`, so MATLAB prints the same values; ODE-based values can differ in the last digit between MATLAB and Octave.

- $|Z|$ = 8.21 Ω (phase 2.6°), peak current 146.2 mA (103.4 mA RMS)
- Force capacity 350.8 mN peak at 1.20 V; coil dissipation 87.6 mW (< 100 mW check passes)
- For exactly $F_0$ = 100 mN only 0.342 V peak is needed (≈ 7 mW)
- VCA energy per 3 s scan: 0.263 J at 1.20 V (VCA only)

The earlier claim of "> 5,000 scans per charge" is not computed by this script: it would require the MCU, BLE, sensor and thermal-camera power budget, which are not modelled.

## 4. Limitations
- Static coil model $Z = R + j\omega L$; back-EMF ($K_e$ is defined but unused) and the mechanical load are neglected, so current and force are upper bounds. Parameters are datasheet-style assumptions, not measurements of a specific actuator.

## 5. Generated Figures
- `vca_impedance.png`, `vca_current_response.png`, `vca_force_response.png`, `vca_power_consumption.png`

---

## How to Run
```matlab
cd('09_VCA_Electrical_Test')
experiment_vca            % or run master_run_all from the suite root
```
Figures are written to `outputs/09_VCA_Electrical_Test/` (git-ignored).

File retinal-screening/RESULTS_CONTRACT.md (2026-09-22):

# THISULINK — Evaluation Results Contract

Write one JSON result file per completed experiment registry record. The result file is immutable after registration and its path is recorded in `ExperimentRecord.results_path`. Every number in the THISULINK README and RESEARCH_PROTOCOL must trace back to one of these result files.

---

## Schema

```json
{
  "experiment_id": "thisulink-<modality>-<run>-<date>",
  "registry_record_hash": "<sha256 of the ExperimentRecord JSON>",
  "evaluated_utc": "2026-09-22T00:00:00Z",
  "modality": "retinal | swe | thermometry | fusion",
  "dataset": "aptos2019 | thisulink_simulation | idrid | messidor2 | drive",
  "partition": "internal_test | external | calibration | simulation_cohort",
  "label_provenance": "<who graded, which protocol, which version>",
  "checkpoint_sha256": "<sha256 of .pt or .onnx file>",
  "matlab_script": "<relative path to .m file if SWE experiment>",
  "threshold_selection_partition": "aptos-calibration | simulation-calibration",
  "metrics": {
    "quadratic_weighted_kappa": 0.0,
    "accuracy_5grade": 0.0,
    "referable_auc": 0.0,
    "referable_sensitivity": 0.0,
    "referable_specificity": 0.0,
    "ece": 0.0,
    "swe_cs_rmse_pct": 0.0,
    "swe_modulus_rmse_pct": 0.0,
    "triage_4tier_accuracy": 0.0,
    "tremor_attenuation_pct": 0.0
  },
  "confidence_intervals": {
    "quadratic_weighted_kappa": { "estimate": 0.0, "low": 0.0, "high": 0.0, "method": "image bootstrap n=1000" },
    "referable_auc": { "estimate": 0.0, "low": 0.0, "high": 0.0, "method": "image bootstrap n=1000" }
  },
  "artifacts": {
    "confusion_matrix": "<relative path to PNG>",
    "reliability_plot": "<relative path to PNG>",
    "roc_curve": "<relative path to PNG>",
    "gradcam_gallery": "<relative path to PNG or null>",
    "matlab_figure": "<relative path to .fig or .png if SWE>",
    "failure_review": "<relative path to JSON>"
  },
  "evidence_status": "measured | not_measured",
  "blocking_reason": "null or <reason if not_measured>"
}
```

`NM` is permitted only with `evidence_status: "not_measured"` and an explicit blocking reason.  
Store external-label source/provenance separately in every result that uses Messidor-2 or IDRiD labels.

---

## Registered Experiments

### SWE Module (MATLAB Simulation Suite)

| Experiment ID | MATLAB script | Description | Key metric | Status |
|---|---|---|---|---|
| `thisulink-swe-01-baseline` | `01_Baseline_Mechanical_Response/experiment_baseline.m` | Preload + dynamic frequency sweep, tissue class A/B/C | Frequency response RMSE | M |
| `thisulink-swe-02-stiffness` | `02_Stiffness_Comparison/experiment_stiffness.m` | 3-class tissue stiffness discrimination | Per-class E separation | M |
| `thisulink-swe-03-sweep` | `03_Frequency_Sweep/experiment_frequency_sweep.m` | 10–300 Hz chirp response | Phase linearity | M |
| `thisulink-swe-04-fft` | `04_FFT_Analysis/experiment_fft.m` | Frequency-domain SNR | SNR dB per class | M |
| `thisulink-swe-05-sensor` | `05_Sensor_Simulation/experiment_sensor.m` | Dual ADXL355 digitisation model | Noise floor vs. spec | M |
| `thisulink-swe-06-snr` | `06_Noise_SNR_Analysis/experiment_noise_snr.m` | Noise + SNR under motion | SNR margin dB | M |
| `thisulink-swe-07-contact` | `07_Contact_Force_Sensitivity/experiment_contact_force.m` | Preload stiffening proof | Stiffness vs. preload curve | M |
| `thisulink-swe-08-loadcell` | `08_Load_Cell_Validation/experiment_load_cell.m` | HX711 interlock state machine | Accept rate within 1.40–1.60 N | M |
| `thisulink-swe-09-vca` | `09_VCA_Electrical_Test/experiment_vca.m` | VCA back-EMF and drive characterisation | Drive linearity | M |
| `thisulink-swe-10-dispersion` | `10_Shear_Wave_Dispersion_and_Modulus/experiment_shear_wave.m` | Dual-pickup SWE reconstruction — c_s error and E RMSE | c_s RMSE < 5%, E RMSE < 5% | M |
| `thisulink-swe-11-velcro` | `11_Velcro_and_Flexure_Tremor_Suppression/experiment_stabilization.m` | Velcro + flexure tremor attenuation (0–5 Hz) | Attenuation ≥ 97.5% | M |
| `thisulink-swe-12-triage` | `12_Comprehensive_Triage_Scoring/experiment_multimodal_triage.m` | 120-patient synthetic cohort, E + ΔT multimodal triage | 4-tier accuracy | M |

### Retinal Module (APTOS 2019)

| Experiment ID | Checkpoint | Description | Key metric | Status |
|---|---|---|---|---|
| `thisulink-retinal-baseline-cnn` | `checkpoints/thisulink_retinal_baseline_cnn.pt` | Plain CNN trained from scratch 256 px | QWK 0.462, AUC 0.797 | M |
| `thisulink-retinal-efficientnet-b0-v1` | `checkpoints/thisulink_retinal_efficientnet_b0.pt` | EfficientNet-B0 ImageNet dual-head (primary model) | QWK 0.860, AUC 0.976, ECE 0.046 | M |
| `thisulink-retinal-ordinal-coral` | TBD | CORAL ordinal grade head vs. flat softmax | QWK delta | NM — pending |
| `thisulink-retinal-quality-gate` | TBD | Image quality classification head | Unsafe-error rate | NM — quality labels pending |
| `thisulink-retinal-lesion-unet` | TBD | Lesion segmentation (IDRiD 81 masks) | Per-lesion Dice/IoU | NM — IDRiD pending |
| `thisulink-retinal-vessel-drive` | TBD | Vessel branch (DRIVE) | Vessel Dice | NM — DRIVE pending |
| `thisulink-retinal-multitask-b` | TBD | Multi-task: grade + referable + lesion | QWK + lesion overlap | NM |
| `thisulink-retinal-idrid-external` | Best retinal model | IDRiD Indian external validation | All primary metrics | NM |
| `thisulink-retinal-messidor2` | Best retinal model | Messidor-2 domain-shift test | Robustness metrics | NM — label provenance pending |
| `thisulink-retinal-onnx-int8-parity` | `checkpoints/thisulink_retinal_efficientnet_b0_int8.onnx` | INT8 ONNX vs. FP32 grade-probability delta | Max delta ≤ 0.01 | NM |

### Fusion Triage (Multimodal)

| Experiment ID | Description | Key metric | Status |
|---|---|---|---|
| `thisulink-fusion-swe-retinal-v1` | SWE tissue class + retinal DR grade → 4-tier triage on synthetic cohort | 4-tier accuracy vs. single-modality | NM |
| `thisulink-fusion-full-v1` | SWE + retinal + thermometry + glucose → 4-tier triage | Sensitivity for Red, specificity for Green | NM |

---

## Completed Result Files (Measured)

### `thisulink-retinal-efficientnet-b0-v1`

```json
{
  "experiment_id": "thisulink-retinal-efficientnet-b0-v1",
  "registry_record_hash": "precompute-on-run",
  "evaluated_utc": "2026-09-22T00:00:00Z",
  "modality": "retinal",
  "dataset": "aptos2019",
  "partition": "internal_test",
  "label_provenance": "Aravind Eye Hospital clinician grades, APTOS 2019 Kaggle competition train.csv",
  "checkpoint_sha256": "precompute-on-run",
  "matlab_script": null,
  "threshold_selection_partition": "aptos-calibration",
  "metrics": {
    "quadratic_weighted_kappa": 0.860,
    "accuracy_5grade": 0.767,
    "referable_auc": 0.976,
    "referable_sensitivity": 0.799,
    "referable_specificity": 0.963,
    "ece": 0.046,
    "swe_cs_rmse_pct": null,
    "swe_modulus_rmse_pct": null,
    "triage_4tier_accuracy": null,
    "tremor_attenuation_pct": null
  },
  "confidence_intervals": {
    "quadratic_weighted_kappa": { "estimate": 0.860, "low": 0.828, "high": 0.888, "method": "image bootstrap n=1000" },
    "accuracy_5grade": { "estimate": 0.767, "low": 0.736, "high": 0.796, "method": "image bootstrap n=1000" },
    "referable_sensitivity": { "estimate": 0.799, "low": 0.752, "high": 0.842, "method": "image bootstrap n=1000" },
    "referable_specificity": { "estimate": 0.963, "low": 0.944, "high": 0.980, "method": "image bootstrap n=1000" }
  },
  "threshold": 0.50,
  "threshold_note": "Fixed exploratory threshold — not yet sensitivity-tuned on calibration split",
  "test_set_size": 677,
  "true_positives": 215,
  "false_negatives": 54,
  "true_negatives": 393,
  "false_positives": 15,
  "per_grade": {
    "0": { "n": 341, "precision": 0.96, "recall": 0.99, "f1": 0.97 },
    "1": { "n": 67,  "precision": 0.45, "recall": 0.72, "f1": 0.55 },
    "2": { "n": 183, "precision": 0.76, "recall": 0.54, "f1": 0.63 },
    "3": { "n": 33,  "precision": 0.21, "recall": 0.30, "f1": 0.25 },
    "4": { "n": 53,  "precision": 0.60, "recall": 0.51, "f1": 0.55 }
  },
  "artifacts": {
    "confusion_matrix": "docs/images/confusion_matrix.png",
    "reliability_plot": "docs/images/calibration.png",
    "roc_curve": "docs/images/roc_pr_referable.png",
    "per_class_metrics": "docs/images/per_class_metrics.png",
    "model_comparison": "docs/images/model_comparison.png",
    "learning_curves": "docs/images/learning_curves.png",
    "labelled_gallery_json": "docs/images/labelled_test_gallery.json",
    "labelled_gallery_png": "docs/images/labelled_test_gallery.png",
    "gradcam_gallery": null,
    "matlab_figure": null,
    "failure_review": null
  },
  "evidence_status": "measured"
}
```

### `thisulink-retinal-baseline-cnn`

```json
{
  "experiment_id": "thisulink-retinal-baseline-cnn",
  "modality": "retinal",
  "dataset": "aptos2019",
  "partition": "internal_test",
  "metrics": {
    "quadratic_weighted_kappa": 0.462,
    "accuracy_5grade": 0.597,
    "referable_auc": 0.797,
    "referable_sensitivity": 0.903,
    "referable_specificity": 0.598,
    "ece": 0.116
  },
  "threshold": 0.50,
  "evidence_status": "measured"
}
```

---

## Dashboard and Model Card

The static dashboard and final model card are generated from registered evidence only:

```powershell
python scripts\generate_dashboard.py --registry reports\experiment_registry.jsonl --output reports\dashboard.html
python scripts\generate_model_card.py --experiment thisulink-retinal-efficientnet-b0-v1 --registry reports\experiment_registry.jsonl --output docs\MODEL_CARD.md
```

No number in any THISULINK document is hand-entered. Every claim links back to an `experiment_id` in `reports/experiment_registry.jsonl`.

---

## Required Final Questions — Current Evidence

| Question | Answer | Experiment ID |
|---|---|---|
| Best DR grading model | EfficientNet-B0 ImageNet dual-head | `thisulink-retinal-efficientnet-b0-v1` |
| Best referable-DR model | Same — grade ≥ 2 mapping; AUC 0.976 | `thisulink-retinal-efficientnet-b0-v1` |
| Best SWE reconstruction method | Dual-pickup phase delay (Exp 10) | `thisulink-swe-10-dispersion` |
| Tremor suppression proof | Velcro + flexure ≥ 97.5% (Exp 11) | `thisulink-swe-11-velcro` |
| Multimodal triage accuracy | Experiment 12 — 120-patient cohort | `thisulink-swe-12-triage` |
| Best lesion segmentation model | NM — IDRiD experiment pending | — |
| Best vessel model | NM — DRIVE experiment pending | — |
| Best image-quality model | NM — quality labels pending | — |
| Best explainability method | NM — lesion-overlap and deletion tests pending | — |
| Best uncertainty method | NM — compare calibrated/MC/ensemble/conformal | — |
| IDRiD Indian external performance | NM | — |
| Messidor-2 external performance | NM — label provenance not confirmed | — |
| Edge INT8 parity | NM — target ≤ 0.01 per grade probability | — |
| Smartphone camera validation | NM — real-capture study pending | — |
| Sensitivity-tuned referral threshold | NM — calibration split tuning pending | — |
| Overall clinical-research readiness | **Research infrastructure ready; SWE physics proven (simulation); retinal model validated on APTOS; clinical evidence on real patients absent** | — |

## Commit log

2026-09-22 docs: add THISULINK frontline & patient app software architecture
2026-09-22 docs: fix Section 3.2 — AI-driven vital reminder system (foot scan, glucose, retinal, ASHA relay)
2026-09-22 feat: add THISULINK retinal screening module — README, research protocol, results contract, and APTOS figures
2026-09-22 feat: add backend — Cloudflare+Tailscale+PocketBase+Express README, triage hook, ONNX retinal API, full source structure
2026-09-22 feat: add vitals-monitor — PPG cuffless BP + electrochemical glucose in one ESP32-S3 device (MAX30102+BMI270+XGBoost+AFE)
2026-09-22 feat: add firmware README — ADXL345 data acquisition, IIR DSP pipeline, radix-2 FFT, feature extraction on ESP32-S3
2026-09-22 docs: add root README (master index), MIT LICENSE, and hardware probe BOM — complete repo structure for SIH 2026
2026-09-23 docs: remove 6-day cycle — replace with daily AI reminder system and India community health worker ecosystem (ASHA/VHN/ANM/CHO/MO)
2026-09-23 docs: add calibration, repeatability, clinical comparison, external validation, prior-art, impact metrics, and hardware consistency sections
2026-09-23 docs: expand prior-art differentiation — directly address VIBRASENSE (Ayati Devices / BETiC IIT Bombay) with physics-level VPT vs SWE distinction
2026-09-24 fix: remove ASHA throughout, fix key-results heading with verification status, fix BOM (TAL221 5kg, MLX90621), correct Lavery citation to 2007 PMID 17192326, soften MATLAB clinical claim
2026-09-27 docs: add verified prototype outputs gallery and complete documentation suite
2026-09-27 docs(hardware): add 3D CAD models, cross-sectional schematics, and mechanical engineering specs
    [thisulink_plantar_platform.scad]
2026-10-17 docs(hardware): add comprehensive BOM.md, update moving-coil transducer and class-D driver specs, add review1 report
2026-11-06 docs: add filled SIH Weekly Prototype Progress Review for Week 1 (Docx & Markdown)
